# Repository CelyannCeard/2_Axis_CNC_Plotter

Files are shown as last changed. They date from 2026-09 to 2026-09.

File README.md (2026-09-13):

<h1 align="center">🛠️ 2-Axis CNC Plotter / Braille Machine</h1>

<p align="center">
  <i>A 2-axis cartesian writing machine and braille embosser built from scratch (CAD, 3D printing, and Arduino CNC control).</i>
</p>

<p align="center">

</p>

## 📝 Overview
This project was developed during my 3rd year of engineering studies at Polytech Lyon (Industrial Systems & Robotics). The goal was to design, manufacture, and assemble a 2-axis industrial machine. 

Our team built a versatile **XY Plotter** capable of two main functions:
1.  **2D Drawing:** Accurately drawing complex shapes and texts on paper using a pen.
2.  **Braille Embossing:** (Initial scope) Punching relief dots on thick cardboard to create readable Braille documents for visually impaired individuals.

<br>

## ⚙️ My Contributions
As part of a 4-person team, I was the **Mechanical & Hardware Lead**. My responsibilities included:
*   **Mechanical Design (CAD):** I designed all custom structural parts, brackets, and slider mechanisms using **PTC Creo**. The design was inspired by open-source plotters but fully modeled to fit our specific constraints and budget.
*   **Fabrication:** Preparing the models for 3D printing and manufacturing the parts.
*   **System Assembly:** I led the physical assembly of the aluminum extrusions, linear rails, belts, pulleys, and structural 3D-printed parts.
*   **Hardware Integration:** I was responsible for wiring the electronics, including the NEMA stepper motors, the Arduino Uno, the CNC Shield, and the limit switches.

*(Note: The software integration, GRBL flashing, and G-Code generation were handled by my teammates).*

<p align="center">
Capture d'écran 2026-09-13 182711
</p>

<br>

## 📐 Mechanical Architecture
The machine is based on a standard H-bot / Cartesian XY gantry system.
*   **X & Y Axis:** Driven by **NEMA 17 Stepper Motors** paired with GT2 timing belts and 20-tooth pulleys.
*   **Linear Motion:** Ensured by 6mm precision steel rods and linear ball bearings for high stability and smooth translation.
*   **Z-Axis (Toolhead):** A custom toolhead actuated by a micro-servo motor lifts and lowers the pen/puncher.
*   **Structure:** Built around 20x20mm aluminum extrusions, corner brackets, and 3D-printed mounts (available in this repository).

<p align="center">
Capture d'écran 2026-09-13 183243
</p>

<br>

## 📁 Repository Structure
This repository contains the mechanical assets of the project:
*   `/CAD_Parts/`: Contains the `.prt` (Creo) and `.stl` files of the 3D printed components (motor brackets, pulley mounts, toolhead slider, etc.).
*   `Pieces_2Axis.xlsx`: The Bill of Materials listing the mechanical and electronic components.

<br>

## 🚀 Results & Challenges
The machine was successfully assembled and the Arduino CNC Shield correctly received and executed G-Code via ChiliPeppr/GRBL. 
One of the main challenges was the structural rigidity required for the Braille function. Braille dots require precise 2.3mm spacing and significant downward force, which pushed the limits of our 3D-printed toolhead rigidity, leading us to focus primarily on the 2D drawing capabilities for the final demonstration.

<p align="center">

</p>

---
*Project Team: Celyann CEARD (CAD & Assembly), Julien RIOU (Project Manager), Quentin DREULETTE (Software), Lucas GALMAR.*

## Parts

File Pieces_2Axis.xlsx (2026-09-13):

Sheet: Tri
Légende: | à acheter
 | à fabriquer
 | à remplacer/acheter autre
 | à acheter et sans doute à modifier |  |  | description | surface (en mm) | longueur (mm) | nombre | prix unité | Total | liens
 | elec |  | STRUCTURE :
 | pas sur de l'utilité / pas à acheter |  | 1. Beam 0824-16 x1 | structure fabriction 3D | 24x08 | 16 | 1 | 0.00 € | 0.00 €
 |  |  | 2. Beam 0824-48 x4 | structure fabriction 3D | 24x08 | 48 | 4 | 0.00 € | 0.00 €
 |  |  | 3. Beam 0824-80 x1 | structure fabriction 3D | 24x08 | 80 | 1 | 0.00 € | 0.00 €
 |  |  | 5. Beam 0824-96 x4 | structure fabriction 3D | 24x08 | 96 | 4 | 0.00 € | 0.00 €
 |  |  | 6. Beam 0824-112 x2 | structure fabriction 3D | 24x08 | 112 | 2 | 0.00 € | 0.00 €
 |  |  | 7. Beam 0824-496 x2 | profilée alu | 24x08 | 496 | 2 | 4.70 € | 9.40 € | Profilé aluminium 20x20 fente 6 mm (https://www.systeal.com/fr/profiles-aluminium-6-mm/1670-profile-aluminium-20x20-fente-6-mm.html)
 |  |  | 8. Beam 0808-80 x1 | profilée alu | 08x08 | 80 | 1 | 0.00 € | 0.00 €
 |  |  | 9. Beam2424-504 x2 | profilée alu | 24x24 | 504 | 2 | 4.78 € | 9.56 € | Profilé aluminium 20x20 fente 6 mm (https://www.systeal.com/fr/profiles-aluminium-6-mm/1670-profile-aluminium-20x20-fente-6-mm.html)
 |  |  | SUPPORT :
 |  |  | 10. Bracket 3x3 x2 | Support en L (troué des 2 côtés en 3x3) |  |  | 2 | 0.00 € | 0.00 €
 |  | Largeur=24 mm Epaisseur= 2 mm Longueur=48 mm | 11. Plate 3x6 x5 | plaque trouée (3ligne de 6) |  |  | 5 | 0.00 € | 0.00 €
 |  |  | 12. Bracket U1 x5 | Support (pièce en U qui doit acceuillir un profilé ou une tige) |  |  | 5 | 0.00 € | 0.00 €
 |  |  | 13. Belt Connector x3 | connecteur de la courroie (petit support carré avec trou au millieu) |  |  | 3 | 0.00 € | 0.00 €
 |  |  | 14. 42BYG Stepper Motor Bracket x2 | support en L avec un grand trou d'un coté |  |  | 2 | 0.00 € | 0.00 €
 |  |  | 39. Base Bracket x1 |  |  |  | 1 | 0.00 € | 0.00 €
 |  |  | 40. LS Bracket V2.0 x4 | Support qu'il faudra modéliser et imprimer |  |  | 4 | 0.00 € | 0.00 €
 |  |  | 41. 9g micro servo bracket x1 | servo moteur 9g |  |  | 1 | 0.00 € | 0.00 €
 |  |  | TRANSMITION :
 |  |  | 17. Timing Pulley18T x6 | Poulie crantée 18 dents opposée au moteur |  | 5 | 3 | 3.48 € | 10.44 € | Poulie pour courroie GT2 largeur 6 mm (https://www.systeal.com/fr/pignons-et-courroies/1893-poulie-pour-courroie-gt2-largeur-6-mm.html)
 |  |  |  | roue crantée liée au moteur |  |  |  | 2.90 € | 5.80 € | https://www.systeal.com/fr/pignons-et-courroies/1890-pignon-pour-courroie-gt2-6mm.html
 |  |  | 18. Open-end Timing Belt (1.3m) x3 | courroie |  | 1300 | 3 | 3.48 € | 10.44 € | https://www.lextronic.fr/courroie-5-m-ouverte-78561.html?fast_search=fs (https://www.systeal.com/fr/pignons-et-courroies/1386-courroie-crantee-gt2-6mm.html)
 |  |  | 19. D Shaft 4x56mm x2 | tige alu | 4 (diamètre) | 56 | 2 | 16.56 € | 33.12 € | Arbre de précision diamètre 6 mm (https://www.systeal.com/fr/guidage-lineaire-sur-arbre-de-precision/1880-arbre-de-precision-diametre-6-mm.html)
 |  |  | 23. Linear Motion Shaft D8X496mm x4 | tige alu | 8 (diamètre) | 496 | 4 | 0.00 € | 0.00 € | Arbre de précision diamètre 6 mm (https://www.systeal.com/fr/guidage-lineaire-sur-arbre-de-precision/1880-arbre-de-precision-diametre-6-mm.html)
 |  |  | 24. Linear Motion Slide Unit 8mm x6 | Unité de glissière de mouvement linéaire | 8 (diamètre) |  | 6 | 2.29 € | 13.74 € | https://www.systeal.com/fr/guidage-lineaire-sur-arbre-de-precision/1885-2192-unite-de-roulement-lineaire.html
 |  |  | 20. Threaded Shaft 4x39mm x1 | tige filetée partiellement | 4 (diamètre) | 39 | 1 |  | 0.00 €
 |  |  | 21. Shaft Collar 4mm x10 | collier de serrage pour bloquer les barres tournante | 4 |  | 10 |  | 0.00 €
 |  |  | 22. Flexible coupling 4x4mm x1 | liaison moteur - barre | 4 |  | 1 |  | 0.00 €
 |  |  | 25. Flange Bearing 4x8x3mm x10 | mini roulement a bille |  |  | 2 | 2.23 € | 4.46 € | https://fr.rs-online.com/web/p/roulements-a-billes/6189913?gb=s
 |  |  | 42. Linear Motion Shaft D4x512mm x1 | tige alu | 4 (diamètre) | 512 | 1 | 0.00 € | 0.00 €
 |  |  | 43. Linear Motion Shaft D4x80mm x1 | tige alu | 4 (diamètre) | 80 | 1 | 0.00 € | 0.00 €
 |  |  | FIXATION :
 |  |  | 27. Nut M4 x50 | écrou | M4 |  | 50 |  | 0.00 €
 |  |  | 28. Countersunk Screw M3x8 x10 | vis fraisé | M3 | 8 | 10 |  | 0.00 €
 |  |  | 29. Headless Set Screw M3x5 x26 | vis de serrage sans tête | M3 | 5 | 26 |  | 0.00 €
 |  |  | 30. Plastic Rivet R4060 x16 | rivet R4060 |  |  | 16 |  | 0.00 €
 |  |  | 31. Plastic Rivet R4100 x6 | rivet R4100 |  |  | 6 |  | 0.00 €
 |  |  | 32. Plastic Ring 4x7x2mm x20 | roulement à bille en plastique 4x7x2 |  |  | 20 |  | 0.00 €
 |  |  | 33. Nut M2 x3 Cross recessed pan head screw M2×10 x3 |  | M2 |  | 3 |  | 0.00 €
 |  |  | 34. Hexagon socket button head screws M4×14 x30 | Vis Tête Hexagonale | M4 | 14 | 30 |  | 0.00 €
 |  |  | 35. Hexagon socket button head screws M4×16 x28 | Vis Tête Hexagonale | M4 | 16 | 28 |  | 0.00 €
 |  |  | 36. Hexagon socket button head screws M4×22 x12 | Vis Tête Hexagonale | M4 | 22 | 12 |  | 0.00 €
 |  |  | 37. Hexagon socket button head screws M4×30 x18 | Vis Tête Hexagonale | M4 | 30 | 18 |  | 0.00 €
 |  |  | 38. Hexagon socket button head screws M4×8 x36 | Vis Tête Hexagonale | M4 | 8 | 36 |  | 0.00 €
 |  |  | 44. Cross recessed pan head tapping screws-C ST 2.2×9.5 x10 | Vis crusciforme ST2.2x9.5 |  |  | 10 |  | 0.00 €
 |  |  | 45. Cuttable Linkage 3 x6 | pièce de lego ligne 1x3 clip |  |  | 6 | 0.00 € | 0.00 €
 |  |  | FACILITE D'ASSEMBLAGE :
 |  |  | 46. Nylon cable ties 2*100 x30 | cerflex | 2mm de diamètre | 100mm de longueur | 30 |  | 0.00 €
 |  |  | 47. Rubber band x5 | élastiques |  |  | 5 |  | 0.00 €
 |  |  | ELEC :
 |  |  | 15. K-Power 9g Micro Servo x1 | servo moteur |  |  | 1 |  | 0.00 €
 |  | 17HS19-2004S (https://www.gotronic.fr/art-moteur-17hs19-2004s1-18355.htm) | 16. 42BYG Stepper Motor x2 | Moteur pas à pas |  |  | 2 | 19.50 € | 39.00 € | Moteurs pas-à-pas - Go tronic https://www.lextronic.fr/moteurs-pas-a-pas-nema-17-10823 (https://www.gotronic.fr/cat-moteurs-pas-a-pas-1093.htm)
 |  | arduino | 1. Me-Baseboard x1 | carte basée sur le microcontrôleur ATmega32U4 |  |  | 1 |  | 0.00 €
 |  | sheild cnc | 2. Me Stepper motordriver V1.0 x2 | carte controleur moteur |  |  | 2 |  | 0.00 €
 |  |  | 3. RJ25 Adapter x3 | adapteur arduino RJ45 |  |  | 3 |  | 0.00 €
 |  |  | 4. Wall Adapter Power Supply - 12VDC x1 | Alimentation + cable |  |  | 1 |  | 0.00 €
 |  |  | 5. Micro Switch Button x4 | bouton detecteur placement |  |  | 4 |  | 0.00 €
 |  |  | 6. 6P6C RJ25 cable-20cm x2 | cable RJ45 |  | 200 | 2 |  | 0.00 €
 |  |  | 7. 6P6C RJ25 cable-35cm x1 | cable |  | 350 | 1 |  | 0.00 €
 |  |  | 8. 6P6C RJ25 cable-50cm x2 | cable |  | 500 | 2 |  | 0.00 €
 |  |  | 9. USB A-Male to B-Male Cable x1 | calbe usb - usb b |  |  | 1 |  | 0.00 €
 |  |  |  |  |  |  |  | TOTAL : | 135.96 €

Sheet: Achat
 |  |  |  |  |  |  |  |  | Vue 3d indisponible
description | surface/ diametre | longueur | nombre | prix unité HT | TTC | Total HT | Total | Fournisseur | liens
Moteur pas à pas |  |  | 2 | 16.25 € | 19.50 € | 32.50 € | 39.00 € | Go tronic | 17HS19-2004S (https://www.gotronic.fr/art-moteur-17hs19-2004s1-18355.htm)
courroie |  | 5000 | 1 | 8.33 € | 10.00 € | 8.33 € | 10.00 € | Lextronic | https://www.lextronic.fr/courroie-5-m-ouverte-78561.html?fast_search=fs
Servo moteur |  |  | 1 | 4.13 € | 4.96 € | 4.13 € | 4.96 € | Lextronic | https://www.lextronic.fr/mini-servomoteur-feetech-ft90b-faible-tension-77915.html
carte arduino UNO |  |  | 1 | 18.00 € | 21.60 € | 18.00 € | 21.60 € | Lextronic | https://www.lextronic.fr/arduino-r4-minima-76817.html
carte shield CNC |  |  | 1 | 16.00 € | 19.20 € | 16.00 € | 19.20 € | Lextronic | https://www.lextronic.fr/shield-cnc-pour-arduino-ard-cnc-kit1-78058.html
bouton detecteur placement |  |  | 4 | 2.33 € | 2.80 € | 9.32 € | 11.18 € | Lextronic | https://www.lextronic.fr/micro-switch-microrupteur-a-levier-avec-roulette-10a-wen10184-3127.html
mini roulement a bille | 2024-06-19 |  | 2 | 1.86 € | 2.23 € | 3.72 € | 4.46 € | RS | https://fr.rs-online.com/web/p/roulements-a-billes/6189913?gb=s
profilée alu | 20x20 | 1000 | 2 | 7.90 € | 9.48 € | 15.80 € | 18.96 € | Systeal | Profilé aluminium 20x20 fente 6 mm (https://www.systeal.com/fr/profiles-aluminium-6-mm/1670-profile-aluminium-20x20-fente-6-mm.html)
Poulie crantée 18 dents opposée au moteur | 5 |  | 3 | 2.90 € | 3.48 € | 8.70 € | 10.44 € | Systeal | Poulie pour courroie GT2 largeur 6 mm (https://www.systeal.com/fr/pignons-et-courroies/1893-poulie-pour-courroie-gt2-largeur-6-mm.html)
roue crantée liée au moteur | 6.35 | 20 dents | 3 | 2.90 € | 3.48 € | 8.70 € | 10.44 € | Systeal | https://www.systeal.com/fr/pignons-et-courroies/1890-2205-pignon-pour-courroie-gt2-6mm.html
tige alu | 6 | 1000 | 3 | 6.90 € | 8.28 € | 20.70 € | 24.84 € | Systeal | Arbre de précision diamètre 6 mm (https://www.systeal.com/fr/guidage-lineaire-sur-arbre-de-precision/1880-arbre-de-precision-diametre-6-mm.html)
Unité de glissière de mouvement linéaire | 6 |  | 6 | 3.19 € | 3.83 € | 19.14 € | 22.97 € | Systeal | https://www.systeal.com/fr/guidage-lineaire-sur-arbre-de-precision/1885-2191-unite-de-roulement-lineaire.html
liaison moteur - barre | 4 |  | 1 | 4.90 € | 5.88 € | 4.90 € | 5.88 € | Systeal | https://www.systeal.com/fr/accouplements/1570-accouplement-a-machoire-pour-couple-eleve-635mm-x-8-mm.html
Vis | M5 | 12 | 30 | 0.15 € | 0.18 € | 4.50 € | 5.40 € | Systeal | https://www.systeal.com/fr/visserie-et-divers/1407-lot-de-10-vis-chc-tete-basse-m5x12.html
ecrou frein | M5 |  | 30 | 0.10 € | 0.12 € | 3.00 € | 3.60 € | Systeal | https://www.systeal.com/fr/vis-ecrous-m5/1347-ecrou-frein-m5.html
 |  |  |  |  |  | 85.44 €
 | Go tronic | 39.00 € |  |  |  | 17.09 €
 | Lextronic | 66.94 €
 | RS | 4.46 €
 | Systeal | 102.53 €
 | Total | 212.93 €

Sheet: BOM
 | Liste de materiel
 | acheter : | surface/ diametre | longueur | Nombre | Nom de création
 | Moteur pas à pas |  |  | 2
 | Servo moteur |  |  | 1
 | carte arduino UNO |  |  | 1
 | carte shield CNC |  |  | 1
 | bouton swtich |  |  | 4
 | mini roulement a bille | 2024-06-19 |  | 2
 | profilée alu | 20x20 | 1000 | 2
 | Poulie crantée 18 dents opposée au moteur | 5 |  | 3
 | roue crantée liée aux moteurs | 6.35 | 20 dents | 3
 | courroie |  | 5000 | 1
 | tige alu | 6 | 1000 | 3
 | Unité de glissière de mouvement linéaire | 6 |  | 6
 | liaison moteur - barre | 4 |  | 1
 | Vis | M5 | 12 | 30
 | ecrou frein | M5 |  | 30
 | Créer 3D :
Barre 24x8x16 | petite barre de structure | 24x08 | 16 | 1 | Beam_16
Barre 24x8x48 | petite barre de structure | 24x08 | 48 | 4 | Beam_48
Barre 24x8x80 | petite barre de structure | 24x08 | 80 | 1 | Beam_80
Barre 24x8x96 | petite barre de structure | 24x08 | 96 | 4 | Beam_96
Barre 24x8x112 | petite barre de structure | 24x08 | 112 | 2 | Beam_112
Barre 8x8x80 | petite barre de structure | 08x08 | 80 | 1 | BeamFin_80
support L | petit support en L | 26x26 | 24 | 2 |  | 10
support U | Support pièce en U pour poulie | 28x26 | 24 | 5 |  | 12
 | Support plaque troué | 48x24 | 2 | 5 |  | 11
connecteur courroie | connecteur de la couroie petit support carré avec trou au millieu | 24x24 | 3 | 3 |  | 13
Support Switch | Support pour swtich |  |  | 4 |  | 40
support servo moteur | support servo moteur | 32x36 | 4 | 1 |  | 41
Support L moteur | Support en L pour moteur | 26x2 | 26 | 2 |  | 14

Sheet: Site
Solutions industrielles et composants électroniques | RS (https://fr.rs-online.com/web/)
Farnell France - Distributeur de composants électroniques (https://fr.farnell.com/)
Univers Général - Foussier (https://www.foussier.fr/)
Profilés Aluminium Modulaires & Accessoires | SystéAl (https://www.systeal.com/fr/)
Vente Outillage & Matériel pour Professionnels | WURTH (https://eshop.wurth.fr/)
Makershop | Expert impression 3D en France - Makershop (https://www.makershop.fr/)
RobotShop | Boutique de Robots | Pièces de Robots | Robots en Kits | Robots Jouets (https://eu.robotshop.com/fr)
Robots autonomes, robots mobiles, bras robotiques, cobots (https://www.generationrobots.com/fr/)
Cogibot : Robots éducatifs et Animations événementielles (https://www.cogibot.com/)
Hexadrone France - Spécialiste du drone et créateur du TUNDRA (https://www.hexadrone.fr/)
GoTronic | Robotique et composants électroniques (https://www.gotronic.fr/)
Lextronic distributeur d'accessoires électroniques pour les écoles, les particuliers et les professionnels (https://www.lextronic.fr/)

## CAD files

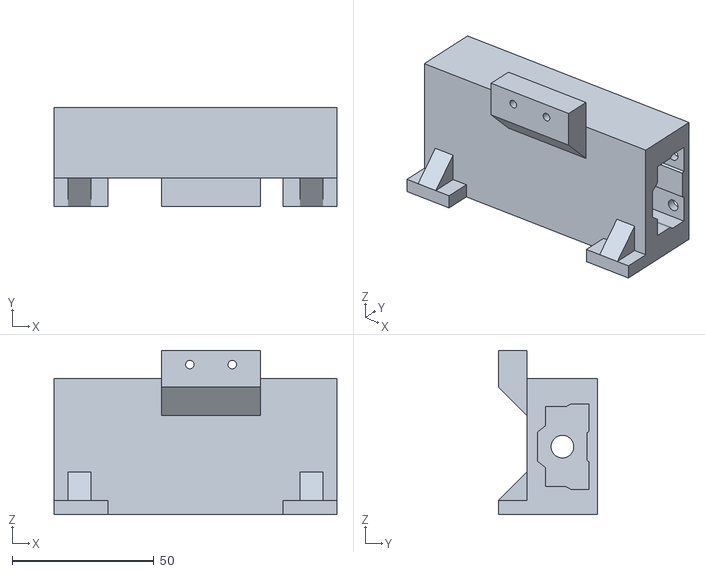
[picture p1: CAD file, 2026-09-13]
CAD_Parts/glissire_porteuse_0001.stl
100.0 x 35.0 x 58.0

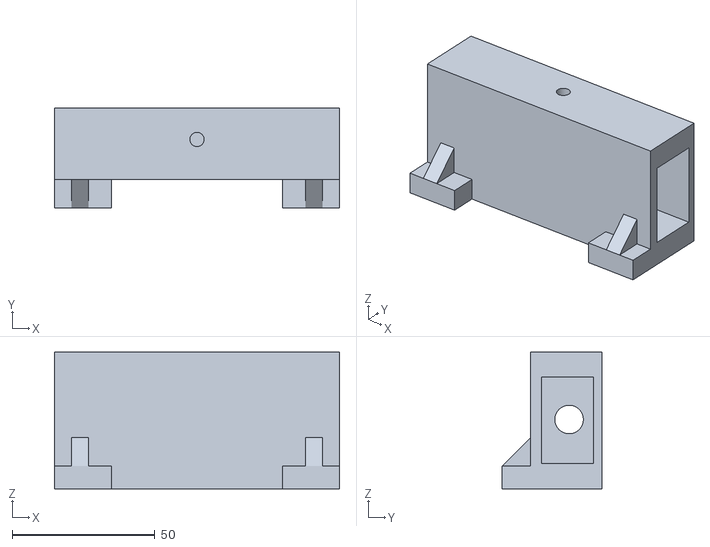
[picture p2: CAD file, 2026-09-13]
CAD_Parts/glissire_porteuse_poulie.stl
100.0 x 35.0 x 48.0

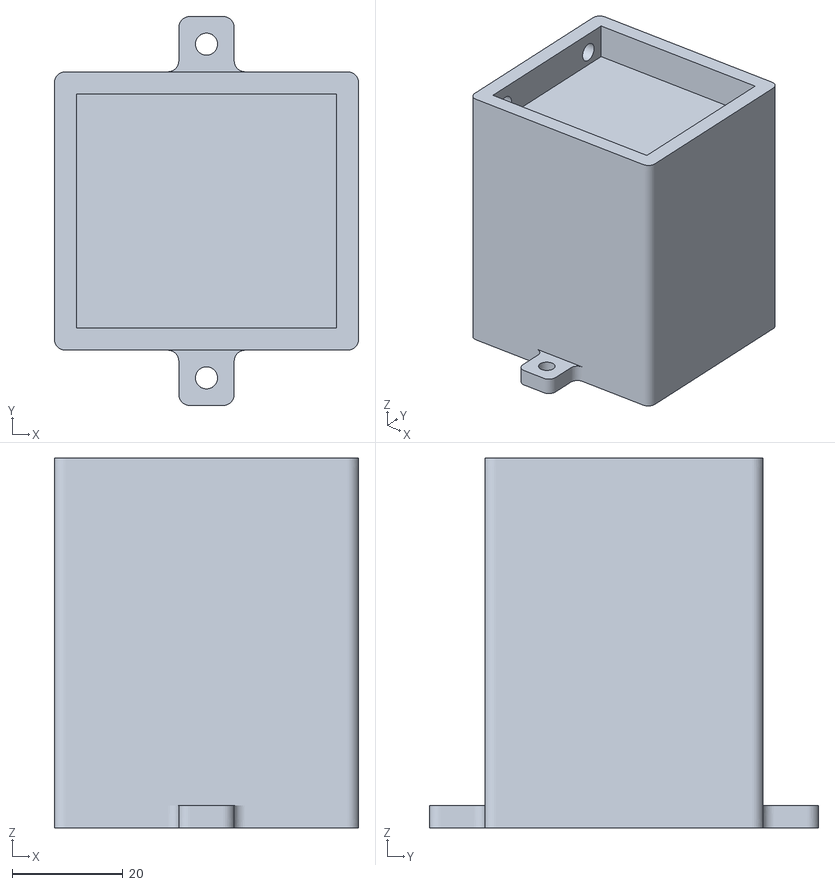
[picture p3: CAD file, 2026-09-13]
CAD_Parts/support_moteur.stl
55.0 x 70.3 x 66.8

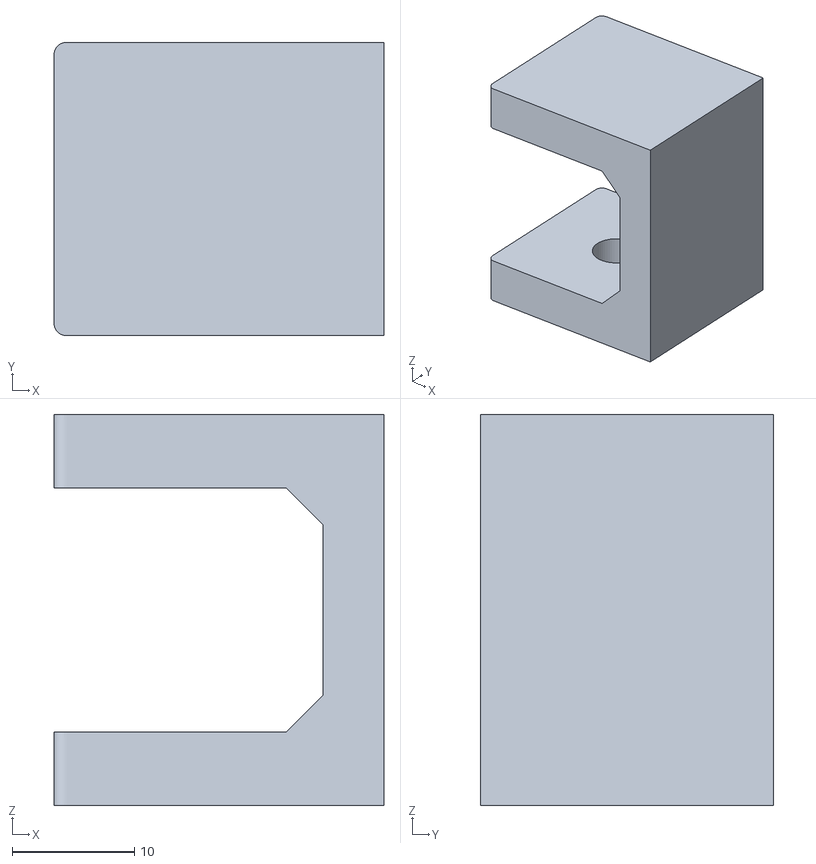
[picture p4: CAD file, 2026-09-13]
CAD_Parts/porte_poulie_simplex2.stl
27.0 x 24.0 x 32.0

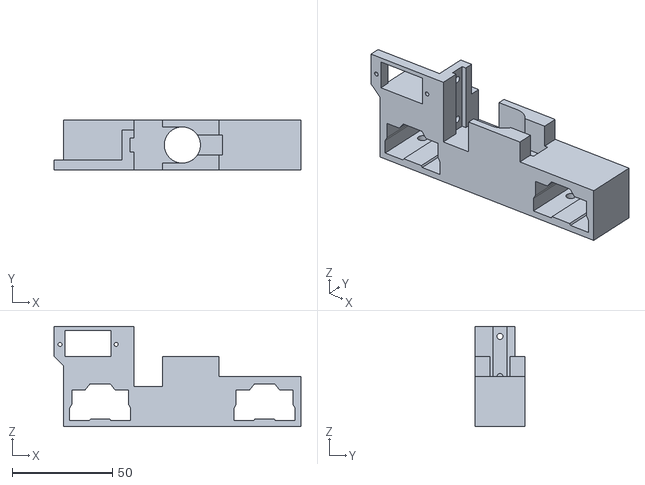
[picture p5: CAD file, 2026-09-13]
CAD_Parts/glissiere_stylo.stl
123.2 x 25.0 x 50.0

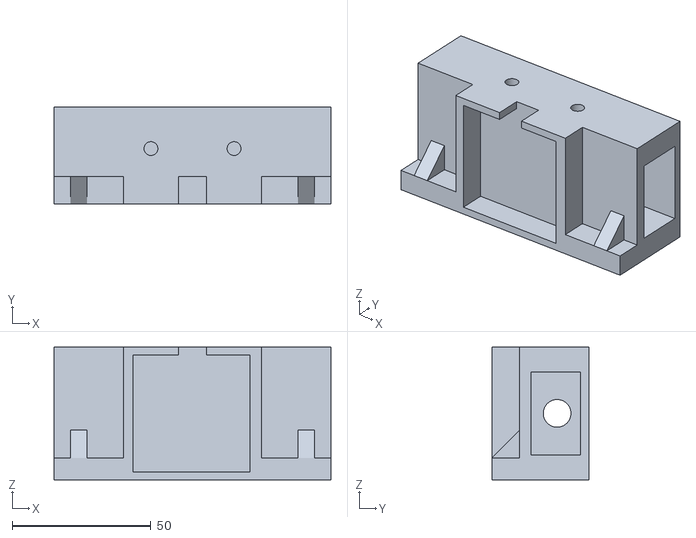
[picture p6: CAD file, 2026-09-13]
CAD_Parts/glissire_porteuse_moteur.stl
100.0 x 35.0 x 48.0

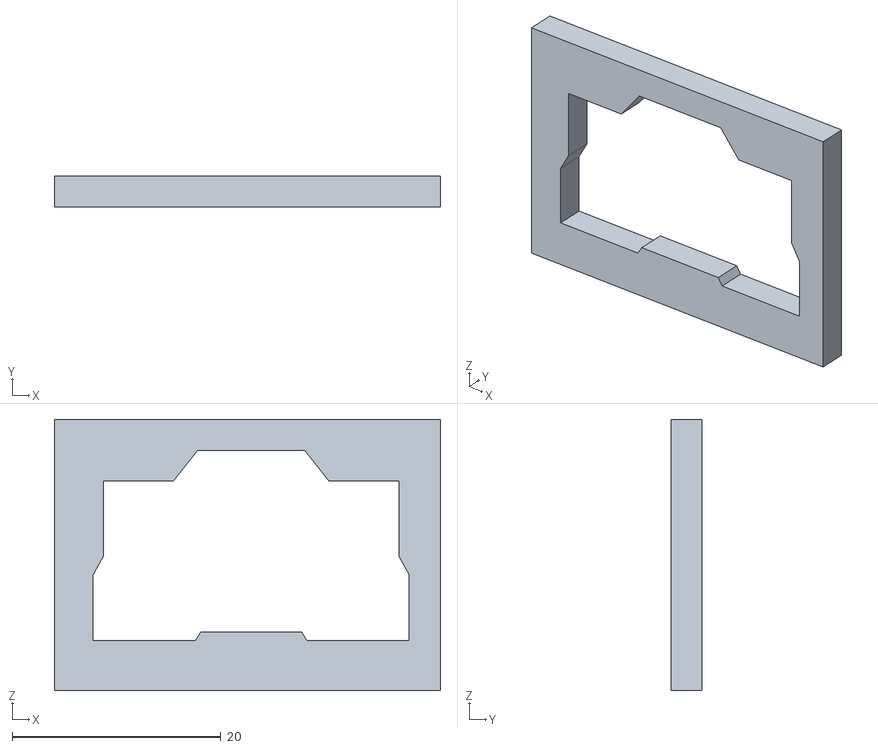
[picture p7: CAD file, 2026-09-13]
CAD_Parts/test_glissiere.stl
37.0 x 3.00 x 26.0

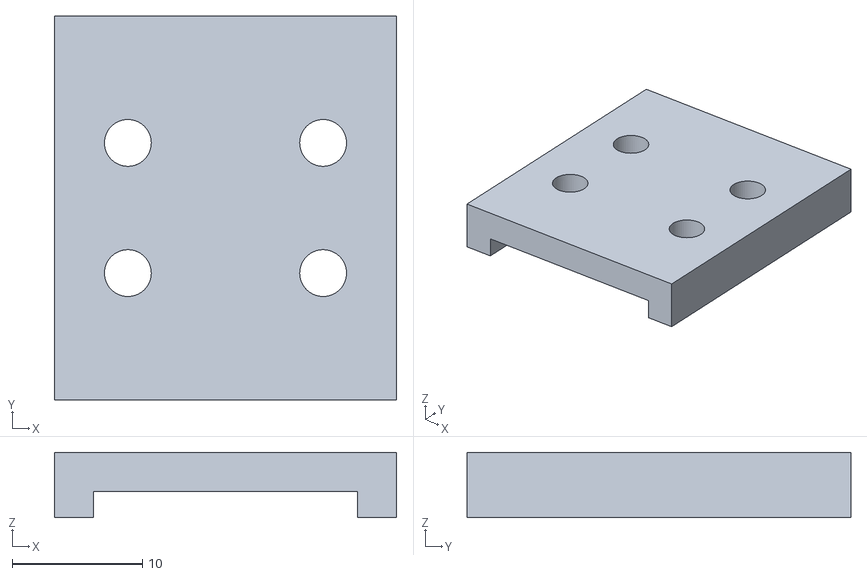
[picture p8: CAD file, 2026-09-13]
CAD_Parts/test1_porte_stylo.stl
26.3 x 29.5 x 5.00

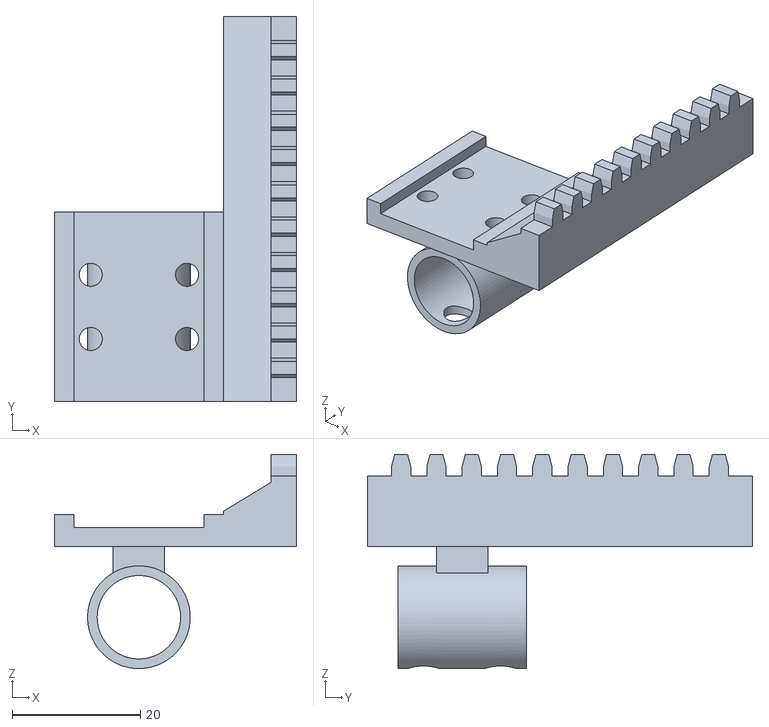
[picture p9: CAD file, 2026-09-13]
CAD_Parts/porte_stylo.stl
37.7 x 60.0 x 33.4

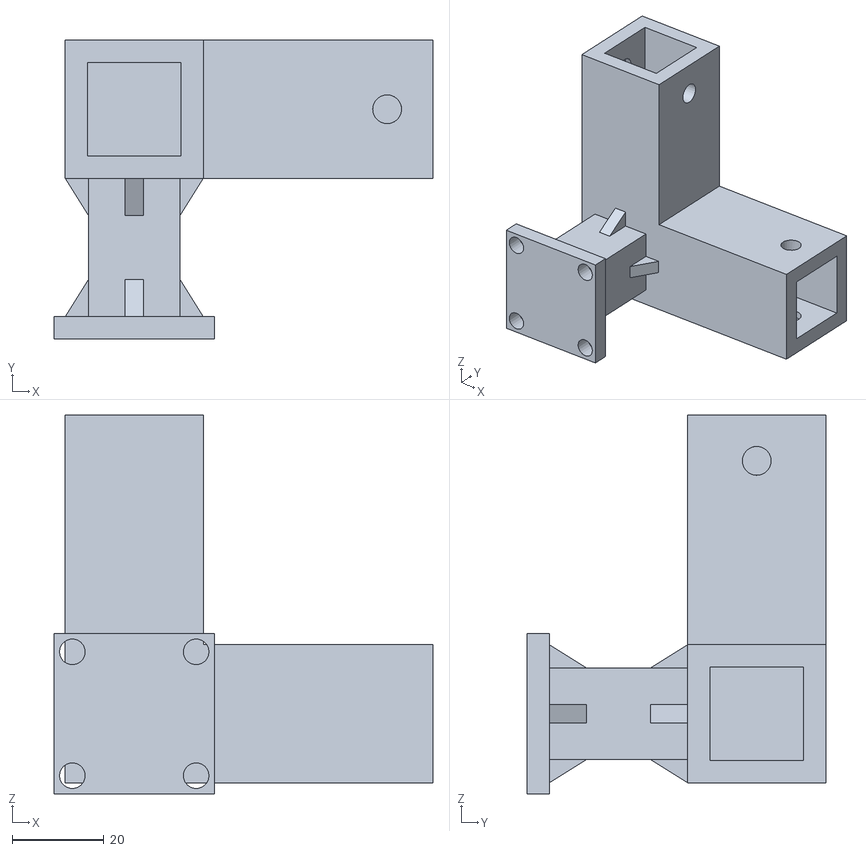
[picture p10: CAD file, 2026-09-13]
CAD_Parts/pied_support.stl
82.7 x 65.3 x 82.7

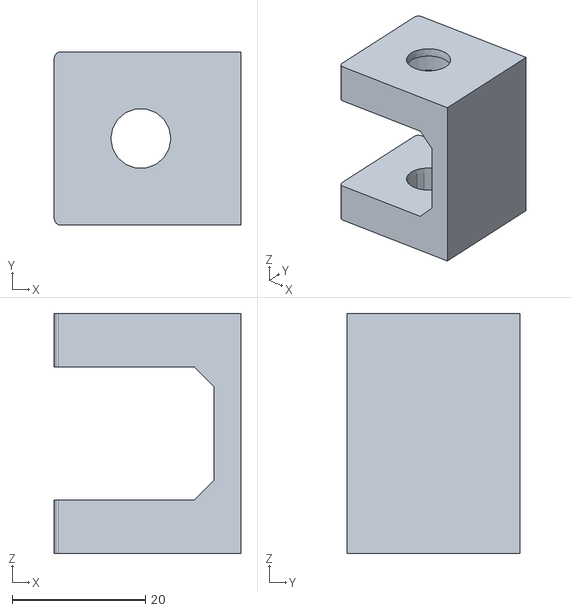
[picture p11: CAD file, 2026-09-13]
CAD_Parts/porte_poulie_moteur.stl
28.0 x 26.0 x 36.0
